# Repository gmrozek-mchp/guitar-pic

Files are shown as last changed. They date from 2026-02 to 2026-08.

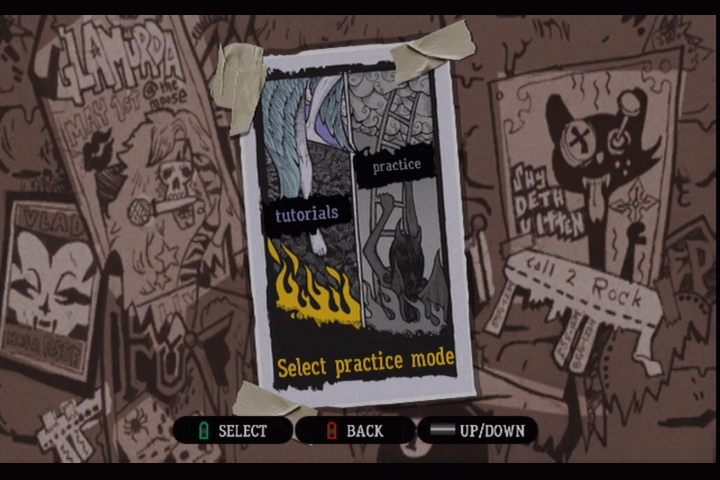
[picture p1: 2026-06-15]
firmware/marvin/docs/gh3_screens/training_menu__tutorials.png

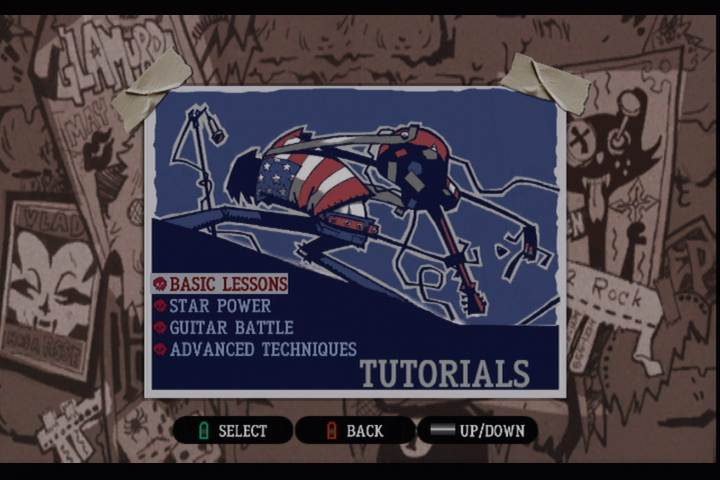
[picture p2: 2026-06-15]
firmware/marvin/docs/gh3_screens/tutorials_menu.png

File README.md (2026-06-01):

# Guitar Hero Bot

An autonomous robot that plays Guitar Hero / Rock Band on a Nintendo Wii by watching the game video, detecting notes in real time, and pressing the buttons on a real Wii guitar controller.

The system is built around a SAM9X75 host (**marvin**) that captures HDMI directly off the Wii, runs reference computer-vision note detection, schedules chord and strum timing, and sends fret/strum commands over USB CDC to a small actuator MCU (**fretboard**) that drives the controller's buttons via open-drain GPIO. A separate Python tool (**fret-tuner**) is used at the bench for calibration and detector tuning, but is not in the runtime path.

For the full system overview see [SPEC.md](SPEC.md).

## Where to start

| If you want to… | Read |
|---|---|
| Understand the whole system | [SPEC.md](SPEC.md) |
| Work on the SAM9X75 host (capture, CV, timing, UI) | [firmware/marvin/docs/spec.md](firmware/marvin/docs/spec.md) + [journal](firmware/marvin/docs/journal.md) |
| Work on the actuator MCU (sensors, GPIO output) | [firmware/fretboard/SPEC.md](firmware/fretboard/SPEC.md) |
| Tune detection algorithms at the bench | [tools/fret-tuner/SPEC.md](tools/fret-tuner/SPEC.md) |
| Inspect marvin performance logs (live or captured) | [tools/marvin-perf/](tools/marvin-perf/) |
| Work on actuator mechanical / PCB / 3D-print parts | [hardware/](hardware/) |

## Repository layout

```
guitar-pic/
├── README.md            # this file
├── SPEC.md              # system spec
├── CLAUDE.md            # workflow rules for Claude Code sessions
├── firmware/
│   ├── marvin/          # SAM9X75 host firmware
│   ├── fretboard/       # PIC32CM6408 sensor/actuator MCU
│   └── sam9x75_curiosity_emirror/   # Microchip reference (template only)
├── tools/
│   ├── fret-tuner/      # Python dev/calibration tool
│   └── marvin-perf/     # marvin performance-log decoder + web viewer
├── hardware/            # PCB, mechanical, actuator design
└── docs/
    ├── SAM9X7-Series-Data-Sheet-DS60001813.pdf
    └── archive/         # historical docs from the original architecture
```

## Status

Working end-to-end: marvin captures HDMI (480p60 and 720p60) and displays live on the LVDS panel; the reference CV detector (`cv_marvin_v1`) runs on captured frames; the timing pipeline and fretboard link (USB CDC over EDBG) are up and gameplay has been tested on Expert and Easy difficulty. The perf-log USB CDC export streams RTOS analytics and pixel strips to a browser-based viewer (`tools/marvin-perf`). Fretboard standalone play (phototransistors + open-drain GPIO) remains operational as a fallback.

In progress: SD-card reference-data recording (M4), full operator UI (M5+). Phasing detail in [SPEC.md §7](SPEC.md).

## License & acknowledgments

MIT License. Hobby / educational project. Guitar Hero and Rock Band are trademarks of Activision and Harmonix; Wii is a trademark of Nintendo.

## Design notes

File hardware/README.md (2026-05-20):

# hardware/

Physical-build artifacts for the guitar-playing robot — PCB, mechanical, and actuator design.

| Folder | What's there |
|---|---|
| [`actuators/`](actuators/) | Design + test-protocol docs for three candidate fret/strum actuator types. The actuator choice is intentionally still open. |
| [`3d-models/`](3d-models/) | OpenSCAD sources and STLs for printed actuator parts. |
| [`Sensor-LCD5/`](Sensor-LCD5/) | KiCad project for the fretboard sensor/actuator PCB (5 phototransistors + open-drain GPIO outputs to a Wii guitar controller). |
| [`kicad/`](kicad/) | Shared KiCad symbol and footprint libraries used by `Sensor-LCD5/` and any future boards. |

## Actuator candidates

Three options are documented under `actuators/`. Each has a design doc and a test-protocol doc.

| Type | Pros | Tradeoffs |
|---|---|---|
| **Voice coil** ([design](actuators/voice-coil-design.md), [test](actuators/voice-coil-test-protocol.md)) | Quietest, fastest, supports proportional control | Most complex to build; custom-wound coil + magnet |
| **Electromagnet** ([design](actuators/electromagnet-design.md), [test](actuators/electromagnet-test-protocol.md)) | Very quiet, simple construction, no moving driver coil | Lower force per watt than a solenoid |
| **DIY solenoid** ([design](actuators/diy-solenoid-design.md)) | Well-understood, predictable behavior | Loudest of the three |

Test protocols measure response time, force, and acoustic noise so the candidates can be compared apples-to-apples before a final pick.

## How this folder relates to firmware

The actuator design docs describe physical drive characteristics (force, response time, current draw). They do not describe the software command path — that lives in the firmware specs:

- The actuator's GPIO-side interface (open-drain pin assignment, pulse durations) is defined by [`firmware/fretboard/SPEC.md`](../firmware/fretboard/SPEC.md).
- The chord and strum scheduling that produces those pulses is described by [`firmware/marvin/docs/spec.md`](../firmware/marvin/docs/spec.md) §4.4.

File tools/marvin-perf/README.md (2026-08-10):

# marvin-perf

Host-side decoder and analyzer for the marvin firmware **perf-log** wire format.

The firmware emits framed binary records (schema version 7) over its USB-device
CDC ACM port. This tool consumes that stream live, records it to disk, and
replays captures offline. Summary analyses (latency attribution, drop
accounting, stack high-water trends) are produced by the `serve` viewer, not a
standalone CLI verb.

Wire format source-of-truth lives in the firmware tree at
[`firmware/marvin/default/src/perf_log/perf_log_records.h`](../../firmware/marvin/default/src/perf_log/perf_log_records.h).
The Python schema mirror in [`marvin_perf/records.py`](marvin_perf/records.py)
must match it byte-for-byte; bump `EXPECTED_SCHEMA_VERSION` (Python side) and
`PERF_LOG_SCHEMA_VERSION` (firmware side) together.

## Setup

All Python work runs through [**uv**](https://docs.astral.sh/uv/). First-time
bootstrap:

    cd tools/marvin-perf
    uv sync --group viewer   # include viewer deps for the serve command

`uv sync` creates `.venv/` and writes `uv.lock`. Subsequent invocations use the
existing venv automatically. Omit `--group viewer` if you only need the headless
CLI helpers (record, set-mask, set-overlay, snapshot, screendump, export-ml).

## Usage

    # Launch the visual review server (default when no subcommand is given)
    # In live mode the SCORE / 2P SC L / 2P SC R toggles each start one device
    # region slot; hit Record to capture them into the .bin like any other
    # record, then extract them offline with `export-region --kind`.
    uv run marvin-perf
    uv run marvin-perf serve
    uv run marvin-perf serve --host 0.0.0.0 --port 8765
    uv run marvin-perf serve --capture session.bin   # pre-load a capture on startup

    # Capture raw bytes from the marvin USB-device CDC port
    uv run marvin-perf record --port /dev/cu.usbmodem... --out session.bin
    uv run marvin-perf record --port /dev/cu.usbmodem... --out-dir session/   # perf.bin + manifest.json

    # Push a type-mask to a running device without attaching for capture
    uv run marvin-perf set-mask --port /dev/cu.usbmodem... --types ALL

    # Toggle the per-fret target rings on the SENSING strip
    uv run marvin-perf set-overlay --port /dev/cu.usbmodem... --on

    # Capture one full video frame from a running device and save it
    uv run marvin-perf snapshot --port /dev/cu.usbmodem... --out snapshots/

    # Dump a UI framebuffer (Legato canvas surface) — the counterpart to snapshot
    uv run marvin-perf screendump --port /dev/cu.usbmodem... --canvas dash
    uv run marvin-perf screendump --port /dev/cu.usbmodem... --canvas navigation
    uv run marvin-perf screendump --port /dev/cu.usbmodem... --canvas navigation \
        --rect 12,120,296,56 --out drawer-row.png

    # Stream a fixed sub-region (default: the scoring block) to PNGs at full rate
    uv run marvin-perf score-capture --port /dev/cu.usbmodem... --out scores/ --count 500
    uv run marvin-perf score-capture --port /dev/cu.usbmodem... --rect 114,309,96,105

    # ...or one of the two 2-player amp scoreboards (independent device slots,
    # so both can stream at once from separate invocations)
    uv run marvin-perf score-capture --port /dev/cu.usbmodem... --slot score-2p-left
    uv run marvin-perf score-capture --port /dev/cu.usbmodem... --slot score-2p-right

    # Extract strips of one kind from a recorded capture into <prefix>-NNNNN.png
    # (5-digit, so a lexicographic sort is frame order up to 99999 frames)
    uv run marvin-perf export-region session/ --out scores/
    uv run marvin-perf export-region session/ --kind score-2p-left --out scores-2pL/
    uv run marvin-perf export-region session/ --kind sensing-2p --out bands-2pL/

### `snapshot` vs `screendump`

They read two memories that share nothing, so neither can show the other's pixels:

* **`snapshot`** captures the **video frame** (the HDMI capture on the HEO hardware
  layer). Use it for anything about what the camera/console is producing.
* **`screendump`** captures a **Legato canvas surface** — the UI framebuffer a screen
  renders into. Use it to inspect widgets, icons and text at the pixel level.

`screendump` takes `--canvas` because every canvas is its own surface: the nav drawer,
the song/mode dialog, the album-art strip and the on-screen keyboard are **not** part
of the base view's buffer. Dump the canvas that owns the pixels you want.

Neither reproduces the panel: the LCDC composites the hardware layers (BASE / HEO /
OVR1 / OVR2) in the display controller, so the blended result exists only on the
glass. `screendump` deliberately does not try to fake it.

    # Export a capture as a SensiML-format CSV for MPLAB ML training
    uv run marvin-perf export-ml session/ --out session.csv --labels actuator-fb

### Capturing 2-player gameplay

Two-player mode moves everything the host cares about: the robot reads the
**left** highway instead of the centered one, and the single bottom-left scoring
block is replaced by **two amp scoreboards** near the top of the frame.

The detector's band strips are tagged per highway, so a capture says which
geometry produced them — `sensing`/`strike` for the 1p centered highway,
`sensing_2p`/`strike_2p` for the 2p left (robot) one. The switch is automatic
during a 2p song (marvin's screen classifier) and forceable from marvin's console
with `cvcfg 2pl`. Both kinds are gated by the STRIP type mask, as before.

The scoreboards ride the region-stream slots. The device has three independent
slots, each with its own enable and rect, each emitting its own strip kind:

| slot | `--slot` / `--kind` | strip kind | default rect |
|---|---|---|---|
| 0 | `score` | `region` | `114,309,96,105` (1p scoring block) |
| 1 | `score-2p-left` | `score_2p_left` | `128,164,68,78` |
| 2 | `score-2p-right` | `score_2p_right` | `515,164,68,78` |

Rects are host-supplied, so any slot can be repointed without a firmware
rebuild. Every slot streams at the full frame rate and there is no rate control:
over-subscribing the wire drops strips at the device's strip pool, counted in
`DROP.dropped_strip`. Capture the note bands and the scoreboards in **separate
sessions** rather than trying to fit both.

## Tests

    uv run pytest

Fixtures under [`tests/fixtures/`](tests/fixtures/) are hand-built byte streams
covering one frame per record type plus framing edge cases (FCS mismatch,
truncated payload, mid-stream join needing SOF resync).

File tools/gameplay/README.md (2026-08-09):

# gameplay — GH3 game-state engine (offline prototype)

Host-side prototype for marvin's game-state observer/controller (spec §4.8, milestone
M9/M10). Algorithms are proven here against the real-screen corpus, then the proven,
simple logic ports to a firmware `gameplay_engine` module. See
[`docs/journal.md`](docs/journal.md) and `firmware/marvin/docs/gh3_navigation.md`.

So far:
- **Screen classifier** — which GH3 screen is this (`main_menu`, `song_select`, `in_song`,
  …) or `UNKNOWN`.
- **Static-list selection reader** — within a recognized static-list screen, which menu
  item is highlighted.
- **song_select reader** — which song is in the highlight slot (and which setlist).
- **Navigator (M10)** — plan a high-level verb (practice-run a song on a difficulty) and
  execute it closed-loop along the menu graph, verified against a simulated menu and the real
  observer.

## Screen classifier

Coarse **fixed-region colour fingerprint** + **nearest-centroid** classifier with an
**UNKNOWN reject** rule (Q10: fixed-region matching, not general CV). A frame is split
into a `cols×rows` grid; each region collapses to its mean BGR; the concatenated vector
is compared by integer L1 distance to one centroid per screen class. The design is shaped
to port to cheap integer C and is **memory-bound, not compute-bound** on the SAM9X75.

Two knobs (chosen empirically by `gameplay eval`, defaults baked into `FingerprintConfig`):

- **sample density** — dense (every pixel; ~7–20 ms on-device) vs a sparse N×N lattice per
  region (sub-millisecond). Default: 5×5 lattice.
- **normalization** — per-frame value standardization, which cancels the **gain/offset
  value-slop** of the Wii's analog-component → HDMI path. Default: on (it is what lifts
  slop-robustness to ~99.8%).

Default config (12×8, 5×5 samples, normalized): 96% leave-one-out accuracy (= 100% of all
multi-sample classes; the 4 single-sample classes can't be LOO-matched), ~99.8% robustness
across the synthetic analog-slop envelope, ~0.1–0.4 ms estimated per classification.

## Static-list selection reader

For the 8 fixed-count static-list screens, per-screen menu metadata (ordered items +
menu-band geometry, in `metadata.py`) divides the band into one cell per item. The selected
cell is the one that deviates most from its **unselected baseline** (learned per screen from
the corpus) — GH3 marks selection by *changing* a row (colour/bar), not by making it
brightest, so "what changed" is the robust signal. Cell colours are normalized per frame to
cancel gain/offset slop. Result: 100% clean / ~99.4% slop on the 33 labelled frames.

## song_select reader

The selected song sits in a fixed highlight slot (except each setlist's first song, which
sits one row lower). We identify it by matching the slot's low-res grayscale bitmap against
the 64 per-song templates — across **both** setlists, so main/bonus falls out of the match.
A small read-time offset search re-aligns the slot, which makes the fine grid tolerant of
positional slop. Result: 64/64 clean, ~99.1% under slop. The active setlist is also read
independently from the page background colour (main = yellow, bonus = white; warmth R−B):
100% clean and under slop.

Char-level OCR is deliberately out of scope: menu items and song titles are a closed set we
already have reference bitmaps for (match, don't decode); digit OCR comes only with score
reading. `section_select` (variable list) and reading the scrolling neighbour list are deferred.

## 2-player amp scoreboard reader

Two-player mode replaces the single bottom-left scoring block with two amp scoreboards near
the top of the frame. `amp2p.py` registers each side independently against its static chrome
(hand-painted `amp2p_<side>_mask.png`), then reads the green LED score inside the registered
block. The strip is a **fixed grid** — 7 px cells at pitch 9, band rows 14–23, right-aligned
against a fixed edge — so there is no ink segmentation: cell positions come from `AMP2P_GRID`
and each is matched by integer coverage L1 against a template bank. Two details carry the
accuracy: the ink threshold is relative to *each cell* (the LEDs pulse, and a band-wide
threshold thins a dim `9` into a `5`), and each digit keeps **two** templates rather than one
average (its bloomed and thin renderings). The font is not segment-decodable — `1` is a centred
bar, `4` and `7` have diagonals.

Which cells hold a digit is read off the display, not the matcher: unused leading cells are
unpowered, so a per-cell contrast gate gives the digit count. Anything the grid cannot justify
— a non-right-aligned lit pattern, a digit count outside the table, ink off the grid — returns
no value with `layout_unknown` set, rather than a guess. Result: **3027/3027** frames of the
reference right-side capture read with 0 monotonic violations, and a bank built from 10
committed right-side frames reads the **left** amp in all 5 corpus snapshots exactly.

Deferred (see `docs/journal.md`): star-power pill count, the centre face-off gauge, and the
multiplier. Scores above 99999 re-lay-out the strip and are flagged, not read.

## Navigator (M10)

`navgraph.py` encodes the menu graph (`firmware/marvin/docs/gh3_navigation.md`) as data;
`navigator.py` plans a verb (`plan_practice_run`, `plan_goto`) and runs it closed-loop through
an `Observer`/`Actuator` seam. The controller is observation-driven — each step runs against
the screen actually observed — which yields normal progress, the `part_select` skip, and RED
recovery from one rule. Offline it's driven by `simgame.py` (the test oracle); on the device
the same seam takes the CV observer + fretboard link. Selections strum the signed delta from
the observed cursor (sticky-safe); FULL SONG/FULL SPEED strum up until the selection stops
moving (no blind count).

## Usage

```sh
uv sync --group dev

uv run gameplay eval                 # classifier + selection reader: accuracy, robustness, thresholds, HW time
uv run gameplay eval --no-sweep      # skip the parameter sweep
uv run gameplay classify path/to/frame.png   # screen id (+ selection / song)
uv run gameplay rows path/to/frame.png       # debug per-cell selection scores
uv run gameplay read-score path/to/frame.png            # 1p score reader on one frame
uv run gameplay read-amp2p path/to/frame.png --side left  # 2p amp score reader on one frame

# 2p amp capture workflow (marvin-perf provides the frames)
#   cd ../marvin-perf && uv run marvin-perf export-region <cap> --kind score-2p-left --out /tmp/L
uv run gameplay amp2p-monotonic /tmp/L --side left      # label-free sweep over a whole capture
uv run gameplay amp2p-grow /tmp/L --side left           # propose new corpus frames (add --commit)

uv run gameplay navigate --song 19 --difficulty hard   # plan + run a practice run vs the sim
uv run gameplay export-c --out gameplay_metadata.h     # freeze recognizer metadata to a C header

uv run pytest
```

## Firmware port (marvin `gameplay_engine`, spec §4.8)

The proven algorithms are being ported to marvin firmware in phases (see `docs/journal.md`).
Phase 0 (done) is `gameplay export-c`: it emits all recognizer data — classifier
centroids/thresholds, static-list menu geometry + baselines, song templates/ROIs — as a single
generated C header (`gameplay_metadata.h`, plain PODs + flat arrays) that the firmware compiles
in. Floats are only the per-frame-normalized baselines/song vectors (soft-float on the ARM926).
The generated header is verified to compile under `cc -std=c11 -Wall -Wextra`.

The corpus is read from `firmware/marvin/docs/gh3_screens/` (override with
`$GAMEPLAY_CORPUS_DIR`). Labels come from each filename's prefix.

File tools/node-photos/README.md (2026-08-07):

# node-photos

Prepares the per-node board photos shown on marvin's **System Info** detail screen.

Drop one photo per node in `data/`, named for the node, then:

```bash
cd tools/node-photos
uv run process_node_photos.py
```

That writes `288x620` PNGs into `firmware/marvin/data/system/nodes/`, which is the
card image tree — copy it to the SD card (or point `--out` straight at the card).

Node names must match the `PHOTO` table in
`firmware/marvin/default/src/ui/node_art.c`:

```
marvin  fauxmote  guitar  fretboard  beatbox  lemmy  lightshow  guitar-pic
```

`guitar-pic` is the whole-rig shot for the project card rather than a node — the
firmware keys it off `0xFF`, outside the T1S id space.

## The frame is baked in

Each output carries its own 1px rounded border (`#404040`, radius 4, corners eaten back to page
black). That is not decoration you can drop: the photo is scanned out on its own hardware layer
above the UI canvas — which is how it keeps 8 bits per channel instead of being quantized to
RGB565 — so no widget can draw a frame over it. Staying opaque over the whole rect is also what
lets the firmware tell the display controller to skip reading the canvas underneath.

Nodes with no photo keep an empty frame drawn by the UI instead.

## Why this step isn't optional

The firmware reads the PNG header and **skips any file that isn't exactly
288x620** (`NODE_ART_W` x `NODE_ART_H` in `ui/node_art.h`), leaving that node's
photo slot empty and the detail screen showing a blank frame. It also has to be PNG:
Legato's JPEG decoder gates its block writes on the renderer clip rect, which is
stale during marvin's offscreen boot decode, so a runtime JPEG decodes to noise.

A missing photo is fine — the loader never fails boot, and the card just reads blank.

## Fit modes

The photo column is tall and narrow (~1:2.15), which almost no camera photo is.

- `--fit contain` (default) — scale the whole photo to fit and letterbox the rest in
  the card's own zinc-900, so the board stays recognizable. Right for landscape shots.
- `--fit cover` — centre-crop to fill the column. Right for a photo already framed
  portrait.

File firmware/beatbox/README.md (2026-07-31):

# beatbox

The **beat-source node** for the Guitar Hero Bot system — a Microchip
**dsPIC33AK512MPS512** DSC that listens to line-level audio, runs real-time FFT
beat detection, and publishes the result to the animation and lighting nodes over
10BASE-T1S: **position commands → [`lemmy`](../lemmy)** and a compact **beat frame →
[`lightshow`](../lightshow)**. It is the system's ear and its choreography brain;
it drives no actuator on the bus itself.

Imported from the standalone `dspicguitarhero` head-banging animatronic and rebuilt
on a fresh MCC config for the MPS512.

## What works today (on the bench)

- **Audio in → beat events.** ADC4 samples stereo line-in at 48 kHz; a 512-point FFT
  extracts spectral-flux / envelope / kick features; a two-band onset detector emits
  discrete beat events. See **[`docs/beat-detection.md`](docs/beat-detection.md)** for
  how the whole chain works.
- **Audio passthrough** to the PWM DACs (RB8/RB9) — a monitor/scratch output, not a
  clean speaker feed (hiss in both the ADC and PWM stages; see the journal).
- **Live RGB indicator.** The onboard LED flashes on beats (kick = white, bass = red,
  mid/high = blue) — a quick visual check that detection is tracking the music.
- **UART2 CLI** for bench control and diagnostics (below).
- **10BASE-T1S PLCA follower (id 5).** Brings up the LAN8651 MAC-PHY, syncs PLCA, and
  announces presence via a heartbeat once a coordinator is on the wire.

Not yet done: publishing beat frames / position commands **on the bus** (milestone
B4), and the **tempo/BPM + phase** layer those need. The imported puppet-motion and
WS2812 effects remain parked in `config.mcc.bak/`.

## Architecture at a glance

Strictly layered, each stage feeding the next; a single stereo sample callback
decouples audio capture from analysis:

```
audio (I/O) → beat_detect (FFT features) → beat_engine (decision) → tempo/phase (later)
```

The heavy DSP runs in the main loop, not the ISR — the 48 kHz ADC interrupt only
buffers samples and hands off via `volatile` flags. Full write-up, including the
no-RTOS cooperation model, in [`docs/beat-detection.md`](docs/beat-detection.md).

| Module (`config.mcc/src/`) | Role |
|---|---|
| `audio.{c,h}` | 48 kHz ADC ISR, DC-block HPF, PWM passthrough, sample callback |
| `beat_detect.{c,h}` | downsample + 512-pt FFT + flux/envelope/kick feature extraction |
| `beat_engine.{c,h}` | onset decision over the features → publishes a `BeatFrame` |
| `t1s_follower.{c,h}` | OA-TC6 / LAN8651 10BASE-T1S PLCA follower |
| `rgb_led.{c,h}` | onboard RGB LED (three SCCP PWM channels) |
| `cli.{c,h}` | UART2 command line (embedded-cli) |

## CLI

Over UART2 (`beatbox>` prompt):

| Command | Purpose |
|---|---|
| `info` | node identity / bring-up state |
| `beat` | latest beat frame — envelope, bass/full flux, kick, beat flags |
| `audio` | raw + filtered L/R sample and peak-to-peak envelope |
| `rgb <r> <g> <b>` / `rgb off` | set the onboard RGB LED (0–255) |
| `t1s` / `t1s id` / `t1s plca` | T1S link status; MAC-PHY id / PLCA diagnostics |
| `reset` | software reset |

## Build

Toolchain: **XC-DSC v3.31**. Build with CMake → Ninja (MPLAB project `beatbox`):

```
cmake -G Ninja \
  -DCMAKE_TOOLCHAIN_FILE=cmake/beatbox/default/.generated/toolchain.cmake \
  -B _build/beatbox/default \
  cmake/beatbox/default
cd _build/beatbox/default && ninja
```

Artifacts: `out/beatbox/default.elf` and `.hex` (flashable). The `cmake/` project tree
is regenerated by MPLAB from `.vscode/beatbox.mplab.json`; `_build/`, `out/`, and
`cmake/**/.generated/` are generated (see [`.gitignore`](.gitignore)).

## Docs

- **How the signal chain works:** [`docs/beat-detection.md`](docs/beat-detection.md)
- **What it is / design / milestones:** [`SPEC.md`](SPEC.md)
- **Decisions & progress:** [`docs/journal.md`](docs/journal.md)
- **System context:** top-level [`SPEC.md`](../../SPEC.md)

## Layout

| Path | Purpose |
|---|---|
| `config.mcc/` | Firmware sources (`src/`) + MCC config (`mcc/`) + generated tree (`mcc_generated_files/`, do not edit) |
| `cmake/` | Generated CMake project (`beatbox/default/`) |
| `.vscode/` | MPLAB project file + workspace settings |
| `docs/` | Signal-chain doc + working journal |
| `SPEC.md` | Specification |

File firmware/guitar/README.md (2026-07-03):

# guitar

Wii-guitar **actuator node** for the Guitar Hero bot's T1S bus. A PIC32CM PL10
(10BASE-T1S PLCA follower) that receives a 1-byte button bitmask from
[marvin](../marvin/) and drives a real Wii guitar controller via open-drain GPIO.

It is the actuation half of the original [fretboard](../fretboard/) firmware, split
onto its own node so sensing (detector nodes) and actuation (guitar nodes) are
separate node classes on one PLCA bus.

- **What it is / firmware design:** [`SPEC.md`](SPEC.md)
- **Decisions + progress:** [`docs/journal.md`](docs/journal.md)
- **System context:** top-level [`SPEC.md`](../../SPEC.md), [`docs/t1s-podl-link.md`](../../docs/t1s-podl-link.md)

Status: working on hardware — the T1S PLCA follower is up, receives and actuates
marvin's command over T1S, and runs a presence heartbeat plus a debug-UART CLI.
See [`SPEC.md`](SPEC.md) for the current milestone state.

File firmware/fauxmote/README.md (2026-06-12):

# fauxmote

ESP32 firmware that emulates a Nintendo Wiimote (with a Guitar Hero guitar
extension) to a real Wii console, on an **Adafruit ESP32 Feather V2** (product 5400).

See [`SPEC.md`](SPEC.md) for what this is and [`docs/journal.md`](docs/journal.md)
for the running plan, decisions, and open questions.

## Build & flash (ESP-IDF v6.x — developed against v6.0.1)

```sh
. $IDF_PATH/export.sh          # activate the ESP-IDF environment
idf.py set-target esp32        # original ESP32 (Feather V2) — has Bluetooth Classic
idf.py build flash monitor     # build, flash over USB-C, open the serial log
```

The board comes up as `Nintendo RVL-CNT-01` and, on a Wii red-SYNC press, pairs and
opens both HID channels (custom SDP record + raw L2CAP; see [`SPEC.md`](SPEC.md) §5
and the journal). Responding to the Wii's reports so it stays an assigned, live
Wiimote is Phase 2.

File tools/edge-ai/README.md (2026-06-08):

# edge-ai

Distill marvin's emitted gameplay commands into a small causal model over the
fretboard's 5-channel ADC stream. **Design + plan live in [`docs/`](docs/)** —
start with [`docs/SPEC.md`](docs/SPEC.md) and [`docs/journal.md`](docs/journal.md).

This package is the host-side pipeline (PyTorch): train a causal CNN, then int8
post-training quantise it into the `model_weights.h` the fretboard firmware runs.
Input is the actuator-labelled CSV from `marvin-perf export-ml --labels=actuator-fb`.

## Layout

- `edge_ai/data.py` — CSV loader + causal row-index windowing (stdlib).
- `edge_ai/lag.py` — photo-dip → strum lag measurement (stdlib).
- `edge_ai/metrics.py` — per-bit accuracy/F1 + strum-event timing (stdlib).
- `edge_ai/model.py` — causal 1D-CNN (`StrumNet`, torch).
- `edge_ai/train.py` — training loop + holdout evaluation (torch).
- `edge_ai/quantize.py` — int8 post-training quantiser + `model_weights.h` emitter (numpy/torch).
- `edge_ai/viz.py` — torchinfo summary, torchview graph, receptive-field cone plot (`viz` group).
- `edge_ai/cli.py` — `edge-ai {lag,train,eval,quantize,viz}`.

The stdlib pieces (`data`, `lag`, `metrics`) run without numpy/torch; only
`model`/`train`/`eval` need the `train` dependency group.

## Use

```sh
export UV_CACHE_DIR="$TMPDIR/uv-cache"   # only needed inside a restricted sandbox

# size the causal window from real data (no torch needed)
uv run edge-ai lag path/to/song-expert.csv --curve

# install the heavy deps and train
uv sync --group train --group dev
uv run edge-ai train --holdout heldout.csv song1.csv song2.csv song3.csv \
    --window 60 --out model.pt
uv run edge-ai eval --model model.pt heldout.csv

# int8 quantise -> firmware header (deploy model: --no-holdout --channels 16 --window 85)
uv run edge-ai quantize --model model.pt --name hard \
    --strum-thresh 0.80 --out ../../firmware/fretboard/model_weights.h song1.csv song2.csv

# visualise the model (summary + RF cone always; graph needs the graphviz binary)
uv sync --group train --group viz   # adds torchinfo, torchview, matplotlib
uv run edge-ai viz --model model.pt --rf-cone rf_cone.png --graph graph.svg

# tests (stdlib-only; needs the dev group for pytest)
uv run --group dev pytest
```

For block diagrams beyond these, export the float model to ONNX and open it in
[Netron](https://netron.app), or redraw in PlotNeuralNet / NN-SVG.

Corpus is Expert-only, one song held out — see [`docs/training.md`](docs/training.md) §4.

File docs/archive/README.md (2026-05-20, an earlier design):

# docs/archive/

Preserved historical documentation from the project's original architecture (≤ 2026-04). The system has since been re-architected; see the top-level [`SPEC.md`](../../SPEC.md) and the subproject specs for current state.

**Files here are kept for design-rationale reference and are not maintained.** Specifically: hardware part numbers, wiring diagrams, calibration steps, and timing assumptions in these documents reflect the *original* PC-hosted / Elgato-USB-capture / PS2 / single-PIC-actuator design — not the current SAM9X75 (marvin) + PIC32CM6408 (fretboard) split.

## What's here

| File | Era | What it describes |
|---|---|---|
| [`SPEC-original.md`](SPEC-original.md) | 2026-01 → 2026-04 | The original full project spec. PS2/Wii console choice, Elgato HDMI-USB capture into a PC running OpenCV, PIC microcontroller driving solenoid actuators. Carries a 2026-05-20 supersession banner pointing at the live subproject specs. |
| [`README-original.md`](README-original.md) | 2026-01 → 2026-04 | The original landing-page README. Quick-start instructions point at the (now deleted) `vision/` Python pipeline. |
| [`hardware-bom.md`](hardware-bom.md) | 2026-01 era | Bill of materials for the original architecture: PIC, solenoids, drivers, 12 V PSU, Elgato capture, PS2/Wii guitar. Useful as a reference for actuator-side parts (drivers, PSU sizing); the host-side parts (capture device, PC) are obsolete. |
| [`wiring-diagram.md`](wiring-diagram.md) | 2026-01 era | Electrical interconnects for the PC ↔ PIC ↔ console era. Pinouts and signal levels are valid as physical-electrical reference; topology is obsolete. |
| [`calibration.md`](calibration.md) | 2026-01 era | Timing-calibration procedure assuming the PC-based scheduler in the now-deleted `vision/` folder. Marvin handles timing on-device; calibration UI for the new architecture lives in marvin (TBD, marvin spec §4.5). |

## Why these are preserved (not deleted)

- The actuator-side design rationale (driver topology, PSU sizing, mechanical mounting, phototransistor placement) is still relevant to the current architecture.
- Latency budgets, calibration math, and detection-threshold approaches in the original docs informed the timing constants now in fret-tuner / fretboard / marvin specs.
- Historical context is occasionally useful when revisiting a design choice.

## Related deletions

The original Python vision pipeline (`vision/`) and its tests (`tests/`) referenced from `README-original.md` were deleted from the working tree on 2026-05-20. They remain recoverable from git history for anyone who wants to compare the original detection algorithms against marvin's reference detector.

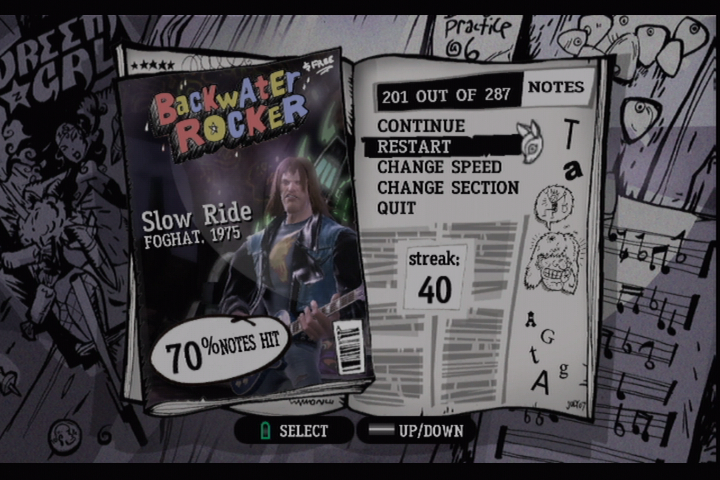
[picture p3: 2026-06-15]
firmware/marvin/docs/gh3_screens/practice_end_menu__restart.png

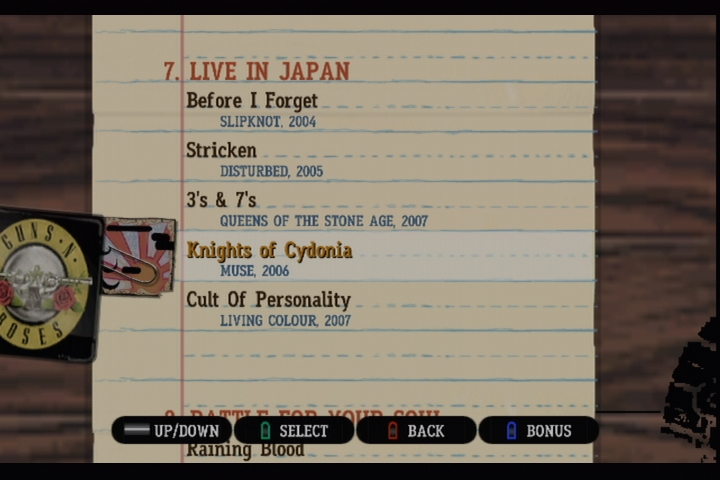
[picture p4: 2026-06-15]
firmware/marvin/docs/gh3_screens/song_select__39_knights_of_cydonia.png

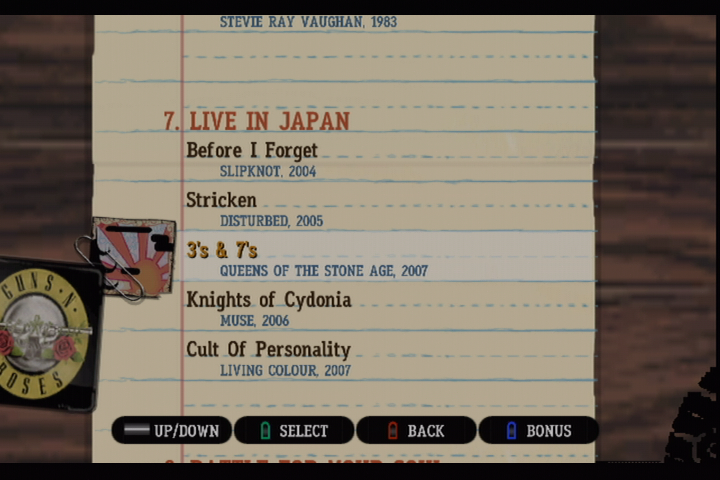
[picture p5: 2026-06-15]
firmware/marvin/docs/gh3_screens/song_select__38_3_s_7_s.png

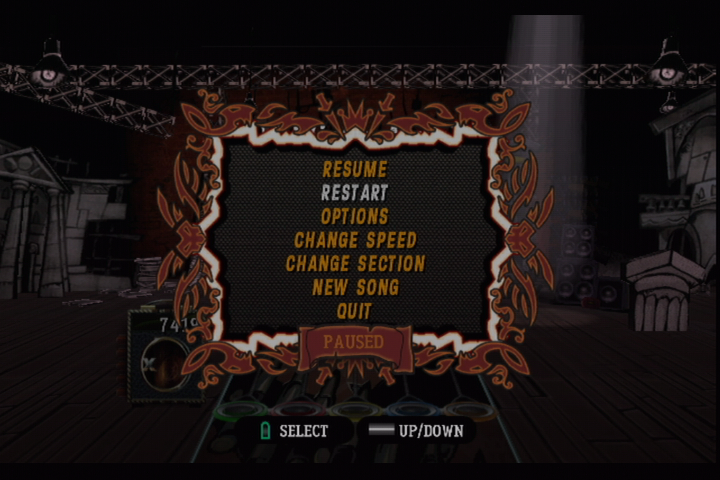
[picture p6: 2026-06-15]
firmware/marvin/docs/gh3_screens/pause_menu__restart.png

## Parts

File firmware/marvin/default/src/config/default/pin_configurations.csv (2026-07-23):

Pin Number | Pin ID | Custom Name | Function | Direction | Latch | Open Drain | PIO Interrupt | Pull Up | Pull Down | Glitch/Debounce Filter | Slew Rate Control | Drive Strength
A2 | PC30 | AC69T88A_ENABLE | GPIO | Out | High | No | Disabled | No | No | Disabled | No | Low
A3 | PC2 | LCD_LVDS_D0_N | LVDSPHY_LVDS_A0M | n/a | n/a | No | Disabled | No | No | Disabled | No | Low
A4 | PC4 | LCD_LVDS_D1_N | LVDSPHY_LVDS_A1M | n/a | n/a | No | Disabled | No | No | Disabled | No | Low
A5 | PC6 | LCD_LVDS_D2_N | LVDSPHY_LVDS_A2M | n/a | n/a | No | Disabled | No | No | Disabled | No | Low
A7 | PC10 | LCD_LVDS_CK_N | LVDSPHY_LVDS_CLK1M | n/a | n/a | No | Disabled | No | No | Disabled | No | Low
A8 | PC12 | LCD_LVDS_D3_N | LVDSPHY_LVDS_A3M | n/a | n/a | No | Disabled | No | No | Disabled | No | Low
A9 | PB19 | QSPI_SCK | QSPI_QSCK | n/a | n/a | No | Disabled | No | No | Disabled | No | Low
A10 | PB17 | LED_8 | GPIO | Out | Low | No | Disabled | No | No | Disabled | No | Low
A11 | PB16 |  | Available | In
B1 | PC28 | LED_5 | GPIO | Out | Low | No | Disabled | Yes | No | Disabled | No | Low
B3 | PC3 | LCD_LVDS_D0_P | LVDSPHY_LVDS_A0P | n/a | n/a | No | Disabled | No | No | Disabled | No | Low
B4 | PC5 | LCD_LVDS_D1_P | LVDSPHY_LVDS_A1P | n/a | n/a | No | Disabled | No | No | Disabled | No | Low
B5 | PC7 | LCD_LVDS_D2_P | LVDSPHY_LVDS_A2P | n/a | n/a | No | Disabled | No | No | Disabled | No | Low
B7 | PC11 | LCD_LVDS_CK_P | LVDSPHY_LVDS_CLK1P | n/a | n/a | No | Disabled | No | No | Disabled | No | Low
B8 | PC13 | LCD_LVDS_D3_P | LVDSPHY_LVDS_A3P | n/a | n/a | No | Disabled | No | No | Disabled | No | Low
B9 | PB21 | QSPI_IO0 | QSPI_QIO0 | n/a | n/a | No | Disabled | No | No | Disabled | No | Low
B10 | PB24 | QSPI_IO3 | QSPI_QIO3 | n/a | n/a | No | Disabled | No | No | Disabled | No | Low
B11 | PB20 | QSPI_CS | QSPI_QCS | n/a | n/a | No | Disabled | No | No | Disabled | No | Low
C1 | PC24 | T1S_nCS | FLEXCOM3_IO4 | n/a | n/a | No | Disabled | No | No | Disabled | No | Low
C2 | PC26 | T1S_SCK | FLEXCOM3_IO2 | n/a | n/a | No | Disabled | No | No | Disabled | No | Low
C4 | PC25 |  | Available | In
C5 | PC27 | LED_6 | GPIO | Out | Low | No | Disabled | No | No | Disabled | No | Low
C7 | PB15 |  | Available | In
C8 | PB23 | QSPI_IO2 | QSPI_QIO2 | n/a | n/a | No | Disabled | No | No | Disabled | No | Low
C10 | PB18 | T1S_IRQ_N | GPIO | In | n/a | No | Falling Edge | Yes | No | Disabled | No | Low
C11 | PB26 |  | Available | In
C17 | PD5 |  | Available | In
D1 | PC20 | LED_BLUE | GPIO | Out | Low | No | Disabled | No | No | Disabled | No | Low
D2 | PC22 | T1S_MOSI | FLEXCOM3_IO0 | n/a | n/a | No | Disabled | No | No | Disabled | No | Low
D3 | PC21 | LED_GREEN | GPIO | Out | Low | No | Disabled | No | No | Disabled | No | Low
D5 | PC29 | LED_7 | GPIO | Out | Low | No | Disabled | Yes | No | Disabled | No | Low
D7 | PC31 |  | Available | In
D8 | PB25 |  | Available | In
D10 | PB22 | QSPI_IO1 | QSPI_QIO1 | n/a | n/a | No | Disabled | No | No | Disabled | No | Low
D16 | PD10 | NAND_D4 | EBI_NANDDAT4 | n/a | n/a | No | Disabled | No | No | Disabled | No | Low
D17 | PB8 |  | Available | In
E1 | PC16 |  | Available | In
E2 | PC18 | LCD_BACKLIGHT_PWM | PWM_PWM0 | n/a | n/a | No | Disabled | No | No | Disabled | No | Low
E3 | PC15 | LED_4 | GPIO | Out | Low | No | Disabled | No | No | Disabled | No | Low
E4 | PC23 | T1S_MISO | FLEXCOM3_IO1 | n/a | n/a | No | Disabled | No | Yes | Disabled | No | Low
E16 | PD14 | NAND_RDY | EBI_NANDRDY | n/a | n/a | No | Disabled | No | No | Disabled | No | Low
E17 | PB14 |  | Available | In
F2 | PC14 | LED_RED | GPIO | Out | Low | No | Disabled | No | No | Disabled | No | Low
F16 | PB6 |  | Available | In
G1 | PC8 | USB_VBUS_SENSE | GPIO | In | n/a | No | Disabled | No | Yes | Disabled | No | Low
G2 | PC0 |  | Available | In
G3 | PC19 |  | Available | In
G4 | PC17 |  | Available | In
G15 | PD3 | NAND_CLE | EBI_NANDCLE | n/a | n/a | No | Disabled | No | No | Disabled | No | Low
G16 | PB0 | LED_2 | GPIO | Out | Low | No | Disabled | No | No | Disabled | No | Low
G17 | PA8 | BUTTON_5 | GPIO | In | n/a | No | Disabled | No | No | Disabled | No | Low
H3 | PC9 |  | Available | In
H4 | PC1 |  | Available | In
H14 | PD1 | NAND_WE | EBI_NANDWE | n/a | n/a | No | Disabled | No | No | Disabled | No | Low
H15 | PD8 | NAND_D2 | EBI_NANDDAT2 | n/a | n/a | No | Disabled | No | No | Disabled | No | Low
H16 | PB2 | BUTTON_6 | GPIO | In | n/a | No | Disabled | No | No | Disabled | No | Low
H17 | PA0 | SDMMC0_DAT0 | SDMMC0_DAT0 | n/a | n/a | No | Disabled | No | No | Disabled | No | Low
J16 | PB4 | LCD_MIPI_SDA | FLEXCOM8_IO0 | n/a | n/a | No | Disabled | No | No | Disabled | No | Low
J17 | PA4 | SDMMC0_DAT2 | SDMMC0_DAT2 | n/a | n/a | No | Disabled | No | No | Disabled | No | Low
K15 | PD12 | NAND_D6 | EBI_NANDDAT6 | n/a | n/a | No | Disabled | No | No | Disabled | No | Low
K16 | PB10 |  | Available | In
K17 | PA2 | SDMMC0_CK | SDMMC0_CK | n/a | n/a | No | Disabled | No | No | Disabled | No | Low
L5 | PA29 | GUITAR_RX | FLEXCOM1_IO1 | n/a | n/a | No | Disabled | No | No | Disabled | No | Low
L13 | PA5 | SDMMC0_DAT3 | SDMMC0_DAT3 | n/a | n/a | No | Disabled | No | No | Disabled | No | Low
L14 | PA11 |  | Available | In
L15 | PB1 | BUTTON_2 | GPIO | In | n/a | No | Disabled | No | No | Disabled | No | Low
L16 | PB12 |  | Available | In
L17 | PA6 | BUTTON_3 | GPIO | In | n/a | No | Disabled | No | No | Disabled | No | Low
M16 | PA10 |  | Available | In
N4 | PA26 | DBGU_RX | DBGU_DRXD | n/a | n/a | No | Disabled | No | No | Disabled | No | Low
N11 | PD0 | NAND_RE | EBI_NANDOE | n/a | n/a | No | Disabled | No | No | Disabled | No | Low
N14 | PD11 | NAND_D5 | EBI_NANDDAT5 | n/a | n/a | No | Disabled | No | No | Disabled | No | Low
N15 | PB5 | LCD_MIPI_SCL | FLEXCOM8_IO1 | n/a | n/a | No | Disabled | No | No | Disabled | No | Low
N16 | PB13 | BUTTON_7 | GPIO | In | n/a | No | Disabled | No | No | Disabled | No | Low
N17 | PA19 | CLASSD_L1 | CLASSD_L1 | n/a | n/a | No | Disabled | No | No | Disabled | No | Low
P8 | PD13 | NAND_D7 | EBI_NANDDAT7 | n/a | n/a | No | Disabled | No | No | Disabled | No | Low
P10 | PD4 | NAND_CS | EBI_NANDCS | n/a | n/a | No | Disabled | No | No | Disabled | No | Low
P11 | PD2 | NAND_ALE | EBI_NANDALE | n/a | n/a | No | Disabled | No | No | Disabled | No | Low
P13 | PD6 | NAND_D0 | EBI_NANDDAT0 | n/a | n/a | No | Disabled | No | No | Disabled | No | Low
P15 | PD7 | NAND_D1 | EBI_NANDDAT1 | n/a | n/a | No | Disabled | No | No | Disabled | No | Low
P16 | PA3 | SDMMC0_DAT1 | SDMMC0_DAT1 | n/a | n/a | No | Disabled | No | No | Disabled | No | Low
P17 | PA17 | T1S_RST | GPIO | Out | High | No | Disabled | No | No | Disabled | No | Low
R1 | PA31 |  | Available | In
R2 | PA25 |  | Available | In
R4 | PA24 |  | Available | In
R5 | PA12 |  | Available | In
R8 | PB3 |  | Available | In
R11 | PD9 | NAND_D3 | EBI_NANDDAT3 | n/a | n/a | No | Disabled | No | No | Disabled | No | Low
R13 | PB7 | BUTTON_4 | GPIO | In | n/a | No | Disabled | No | No | Disabled | No | Low
R14 | PB9 | BUTTON_8 | GPIO | In | n/a | No | Disabled | No | No | Disabled | No | Low
R16 | PA21 | BUTTON_1 | GPIO | In | n/a | No | Disabled | No | No | Disabled | No | Low
R17 | PA18 | CLASSD_L0 | CLASSD_L0 | n/a | n/a | No | Disabled | No | No | Disabled | No | Low
T1 | PA27 | DBGU_TX | DBGU_DTXD | n/a | n/a | No | Disabled | No | No | Disabled | No | Low
T3 | PA30 |  | Available | In
T4 | PA28 | GUITAR_TX | FLEXCOM1_IO0 | n/a | n/a | No | Disabled | No | No | Disabled | No | Low
T5 | PA14 | CLI_RX | FLEXCOM2_IO1 | n/a | n/a | No | Disabled | No | No | Disabled | No | Low
T7 | PA7 | LED_3 | GPIO | Out | Low | No | Disabled | No | No | Disabled | No | Low
T8 | PB11 |  | Available | In
T9 | PA1 | SDMMC0_CMD | SDMMC0_CMD | n/a | n/a | No | Disabled | No | No | Disabled | No | Low
T10 | PA15 | FAUXMOTE_RX | FLEXCOM5_IO1 | n/a | n/a | No | Disabled | No | No | Disabled | No | Low
T11 | PA9 |  | Available | In
U7 | PA20 | BSP_MAXTOUCH_CHG | GPIO | In | n/a | No | Disabled | No | No | Disabled | No | Low
U8 | PA16 | FAUXMOTE_TX | FLEXCOM5_IO0 | n/a | n/a | No | Disabled | No | No | Disabled | No | Low
U9 | PA23 | SDMMC0_CD | GPIO | In | n/a | No | Disabled | No | No | Disabled | No | Low
U10 | PA22 | LED_1 | GPIO | Out | Low | No | Disabled | No | No | Disabled | No | Low
U11 | PA13 | CLI_TX | FLEXCOM2_IO0 | n/a | n/a | No | Disabled | No | No | Disabled | No | Low

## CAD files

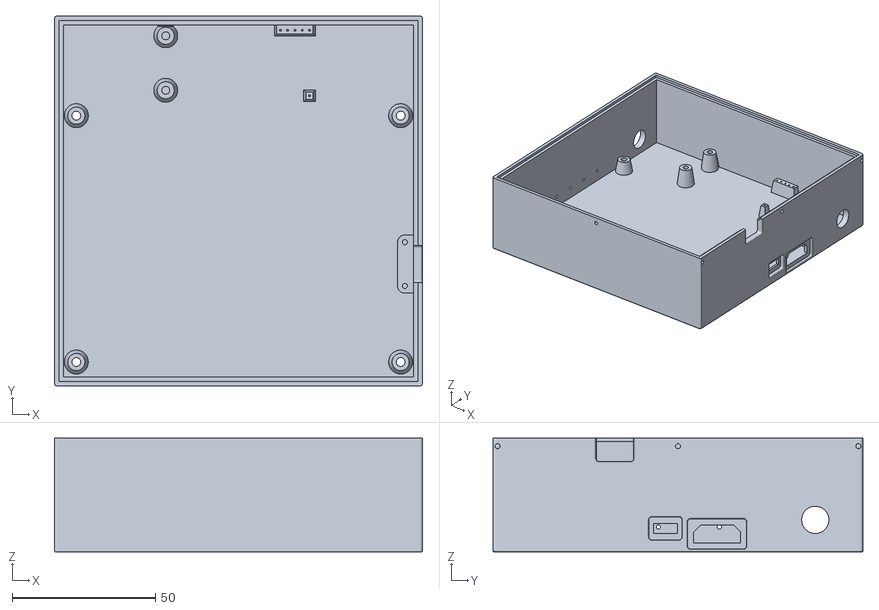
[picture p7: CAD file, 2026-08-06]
hardware/3d-models/Fretboard-Enclosure.stl
128.5 x 129.0 x 39.8

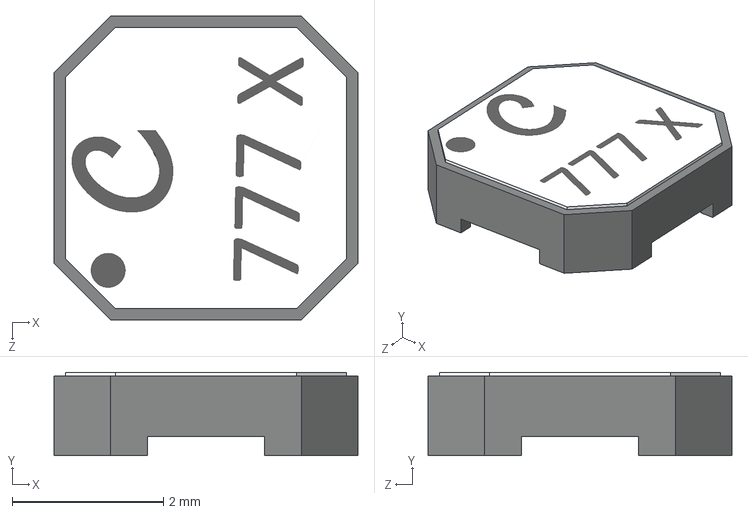
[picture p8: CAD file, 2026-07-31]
hardware/t1s-sink/Coilcraft-LPD4012.STEP
4.02 x 1.10 x 4.02 mm

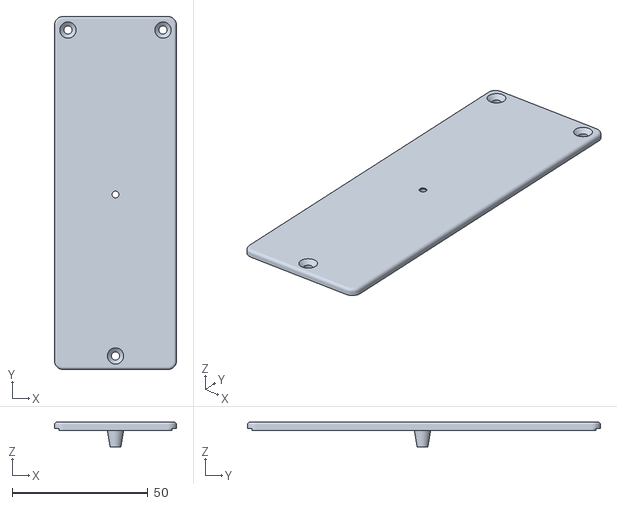
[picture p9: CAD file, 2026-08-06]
hardware/3d-models/EnclosureCover-Lemmy.stl
45.0 x 130.0 x 9.20

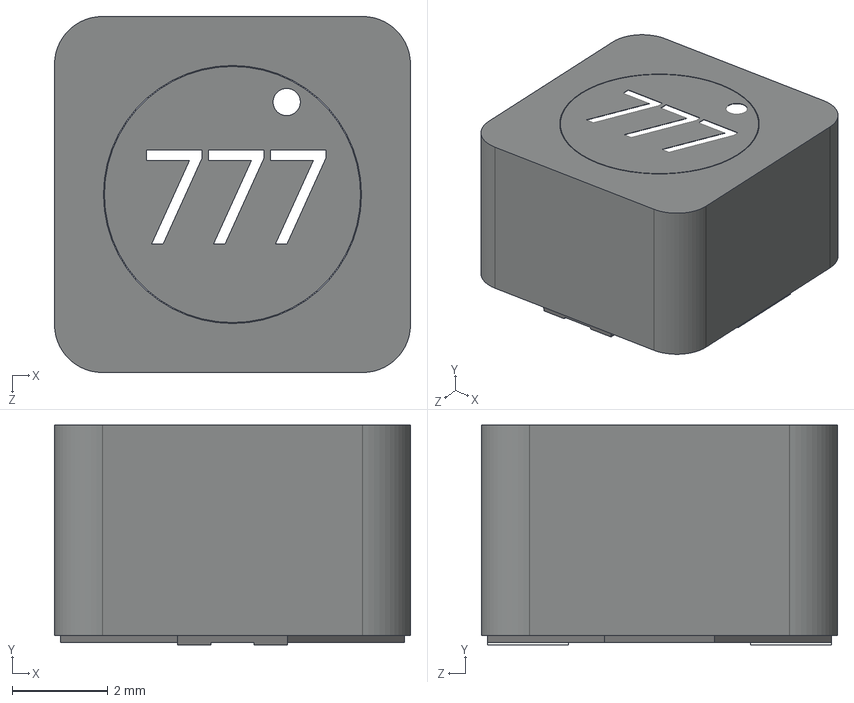
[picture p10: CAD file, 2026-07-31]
hardware/t1s-sink/Coilcraft-MSD7342.STEP
7.45 x 4.60 x 7.45 mm

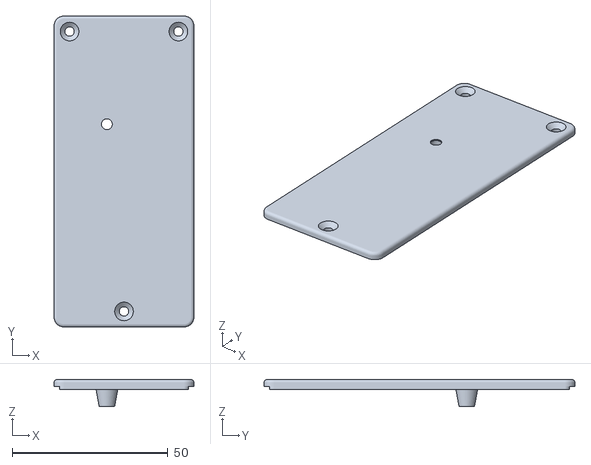
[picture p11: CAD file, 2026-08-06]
hardware/3d-models/EnclosureCover-Fauxmote.stl
45.0 x 100.0 x 8.70

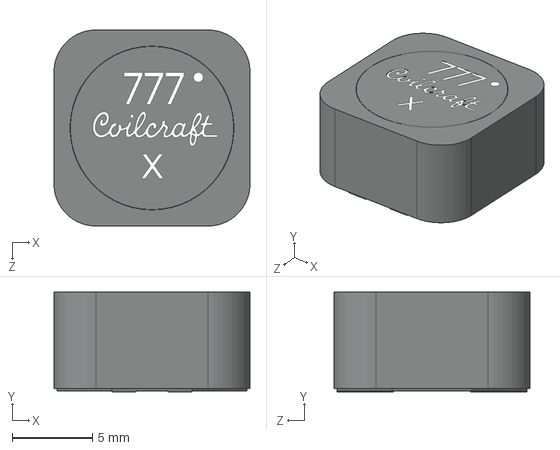
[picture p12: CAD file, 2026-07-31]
hardware/t1s-sink/Coilcraft-MSD1260T.STEP
12.2 x 6.20 x 12.2 mm

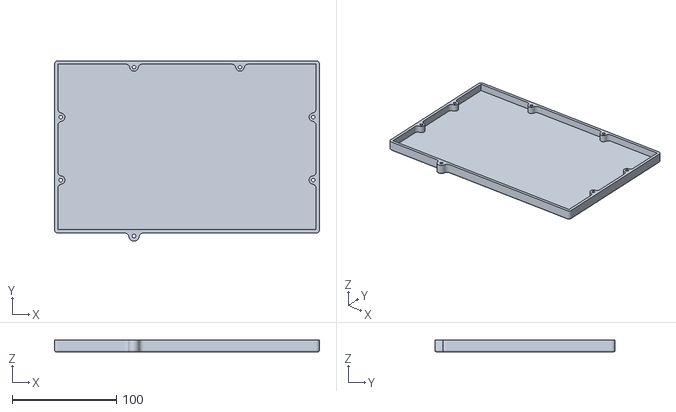
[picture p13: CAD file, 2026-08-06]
hardware/3d-models/Marvin-BackCover.stl
254.0 x 172.9 x 11.2

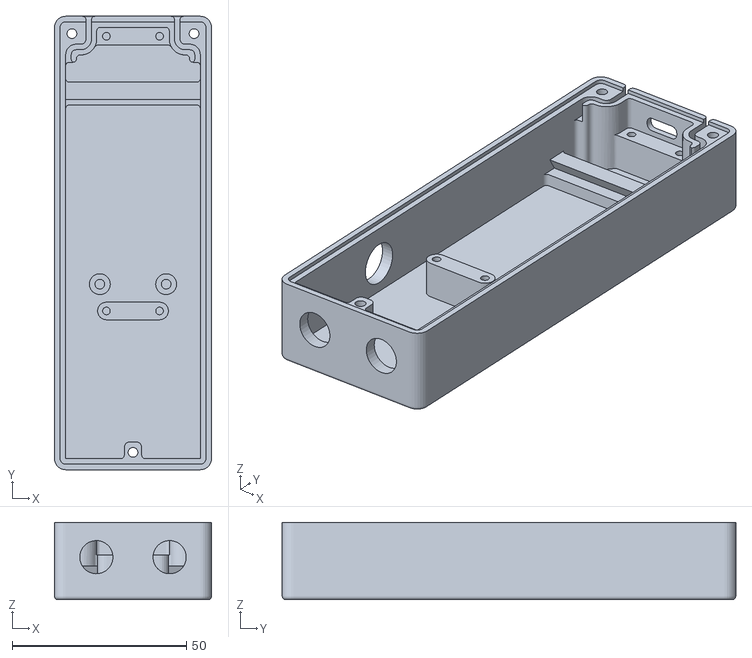
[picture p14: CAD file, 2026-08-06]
hardware/3d-models/Enclosure-Lightshow.stl
45.0 x 130.0 x 22.2

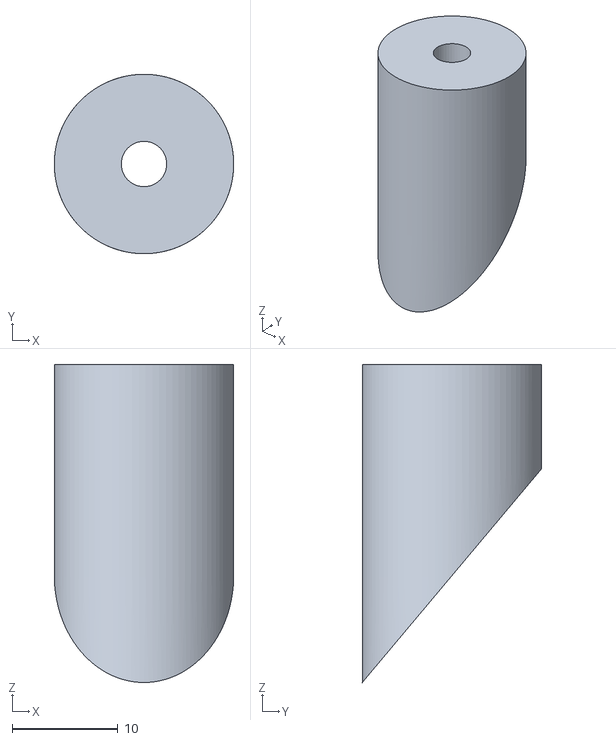
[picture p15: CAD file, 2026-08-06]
hardware/3d-models/LemmyMountTop.stl
17.0 x 17.0 x 30.1

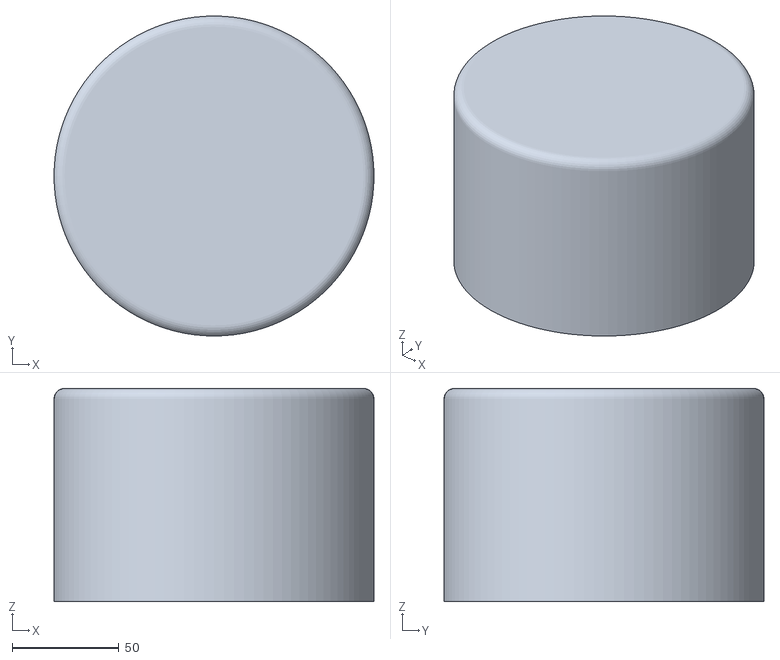
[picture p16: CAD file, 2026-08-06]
hardware/3d-models/HatBlock.stl
150.0 x 150.0 x 100.0

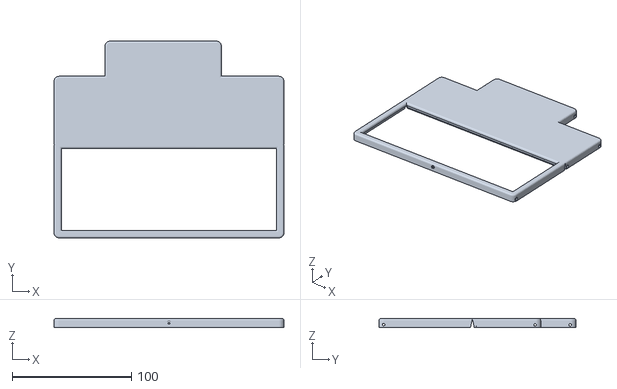
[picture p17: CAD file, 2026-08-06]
hardware/3d-models/BeatBox-Cover.stl
193.3 x 165.4 x 7.61

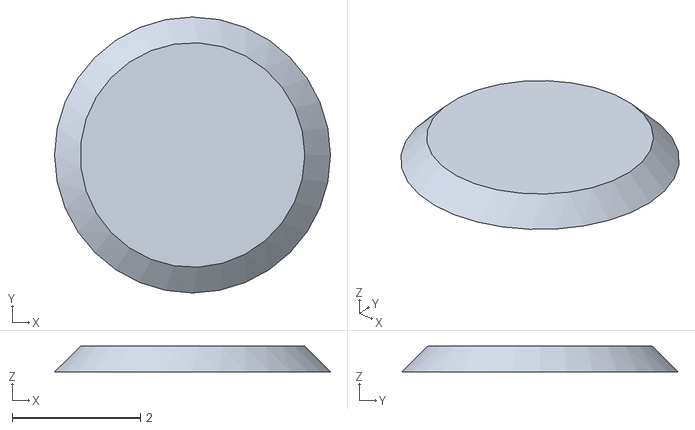
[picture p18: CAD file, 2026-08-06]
hardware/3d-models/EnclosureCover-Fauxmote-LED.stl
4.30 x 4.30 x 0.4

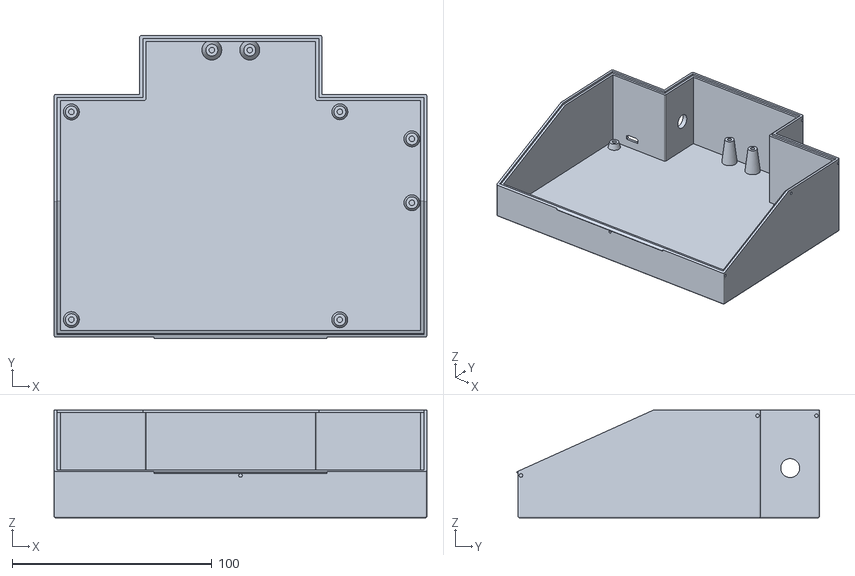
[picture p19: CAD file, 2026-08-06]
hardware/3d-models/BeatBox-Enclosure.stl
186.9 x 152.0 x 54.1

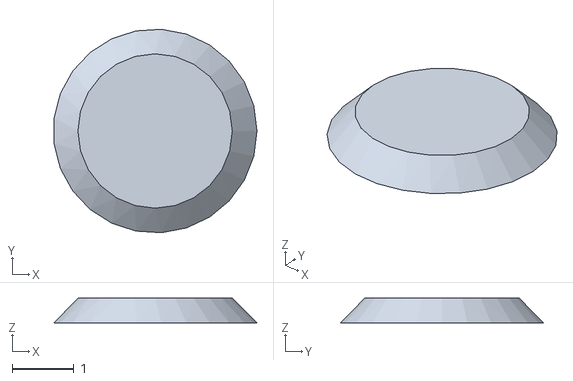
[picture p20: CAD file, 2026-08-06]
hardware/3d-models/EnclosureCover-Lemmy-LED.stl
3.29 x 3.29 x 0.4

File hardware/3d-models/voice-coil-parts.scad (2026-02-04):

// Voice Coil Actuator - 3D Printable Parts
// For Guitar Hero Bot Project
// 
// Designed to fit around Cherry MX compatible keyboard switches
// 
// Usage:
//   1. Open in OpenSCAD
//   2. Enable Customizer: View → Customizer (or View → Hide Customizer to toggle)
//   3. Select part from dropdown in "Part Selection" section
//   4. Render (F6) and Export as STL (File → Export → Export as STL)
//
// Alternative (without Customizer):
//   - Scroll to bottom of file
//   - Change PART = "assembly" to PART = "bobbin" (or housing, wire_guide, print_plate)
//
// Command line export:
//   openscad -o bobbin.stl -D 'PART="bobbin"' voice-coil-parts.scad
//   openscad -o housing.stl -D 'PART="housing"' voice-coil-parts.scad
//   openscad -o wire_guide.stl -D 'PART="wire_guide"' voice-coil-parts.scad
//
// Print settings:
//   - Layer height: 0.15-0.2mm
//   - Infill: 30-50%
//   - Material: PLA or PETG
//   - Supports: Yes for housing (magnet pockets)

// ============================================================
// CONFIGURATION PARAMETERS
// ============================================================

// Switch dimensions (Cherry MX compatible)
switch_width = 15.6;        // Switch body width
switch_depth = 15.6;        // Switch body depth  
stem_diameter = 4.0;        // MX stem cross diameter
stem_socket_dia = 4.3;      // Socket with clearance

// Magnet dimensions (N42 10x5x3mm blocks)
magnet_length = 10.0;
magnet_width = 5.0;
magnet_height = 3.0;
magnet_clearance = 0.2;     // Extra space for fit

// Steel yoke dimensions
yoke_thickness = 2.0;
yoke_width = 10.0;

// Coil dimensions
coil_wire_dia = 0.29;       // 30 AWG with enamel
coil_turns = 60;
coil_layers = 2;
coil_width = 3.0;           // Fits in magnet gap
coil_height = coil_layers * coil_wire_dia * (coil_turns/coil_layers/30);

// Air gap
air_gap = 3.5;              // Space between magnets

// General tolerances
print_tolerance = 0.2;      // General clearance for 3D printing
tight_tolerance = 0.1;      // For press fits

// Derived dimensions
housing_inner = switch_width + 2 * print_tolerance;
housing_wall = 2.0;
housing_outer = housing_inner + 2 * (magnet_width + housing_wall + air_gap/2);

// ============================================================
// HELPER MODULES
// ============================================================

// Rounded rectangle
module rounded_rect(w, d, h, r) {
    hull() {
        translate([r, r, 0]) cylinder(r=r, h=h, $fn=32);
        translate([w-r, r, 0]) cylinder(r=r, h=h, $fn=32);
        translate([r, d-r, 0]) cylinder(r=r, h=h, $fn=32);
        translate([w-r, d-r, 0]) cylinder(r=r, h=h, $fn=32);
    }
}

// Cherry MX stem cross shape (for socket)
module mx_stem_cross(height, clearance=0) {
    stem_long = 4.0 + clearance;
    stem_short = 1.2 + clearance;
    
    union() {
        // Vertical bar
        translate([-stem_short/2, -stem_long/2, 0])
            cube([stem_short, stem_long, height]);
        // Horizontal bar
        translate([-stem_long/2, -stem_short/2, 0])
            cube([stem_long, stem_short, height]);
    }
}

// ============================================================
// BOBBIN (Moving Part)
// ============================================================
// 
// The bobbin holds the voice coil and attaches to the switch stem.
// It moves up and down within the magnetic gap.
//
//              ┌─────────────────┐
//              │   Top surface   │
//              │  ┌───────────┐  │
//              │  │ Stem      │  │
//              │  │ socket    │  │
//              │  │    +      │  │
//              │  └───────────┘  │
//              │  ┌───────────┐  │
//              │  │░░░░░░░░░░░│  │ ← Coil groove
//              │  │░░░░░░░░░░░│  │
//              │  └───────────┘  │
//              └─────────────────┘

module bobbin() {
    bobbin_outer = 18;          // Outer dimension
    bobbin_inner = 10;          // Inner opening (clears switch top)
    bobbin_height = 8;          // Total height
    coil_groove_depth = 2.5;    // Depth of groove for wire
    coil_groove_width = coil_width + 0.5;  // Width with clearance
    stem_socket_depth = 4.5;    // How deep stem inserts
    wall = (bobbin_outer - bobbin_inner) / 2;
    
    difference() {
        // Main body
        translate([-bobbin_outer/2, -bobbin_outer/2, 0])
            rounded_rect(bobbin_outer, bobbin_outer, bobbin_height, 2);
        
        // Inner opening (switch clearance)
        translate([-bobbin_inner/2, -bobbin_inner/2, -1])
            cube([bobbin_inner, bobbin_inner, bobbin_height + 2]);
        
        // Coil groove (rectangular channel around perimeter)
        coil_groove_inner = bobbin_inner + 0.5;
        coil_groove_outer = bobbin_outer - 1.0;
        
        difference() {
            translate([-(coil_groove_outer)/2, -(coil_groove_outer)/2, bobbin_height - coil_groove_depth])
                cube([coil_groove_outer, coil_groove_outer, coil_groove_depth + 1]);
            
            translate([-(coil_groove_inner)/2, -(coil_groove_inner)/2, bobbin_height - coil_groove_depth - 1])
                cube([coil_groove_inner, coil_groove_inner, coil_groove_depth + 3]);
        }
        
        // Stem socket (MX cross shape)
        translate([0, 0, -1])
            mx_stem_cross(stem_socket_depth + 1, 0.3);
        
        // Wire exit slots (two opposite sides)
        wire_slot_width = 2;
        wire_slot_depth = 3;
        translate([-bobbin_outer/2 - 1, -wire_slot_width/2, bobbin_height - wire_slot_depth])
            cube([wall + 2, wire_slot_width, wire_slot_depth + 1]);
        translate([bobbin_outer/2 - wall - 1, -wire_slot_width/2, bobbin_height - wire_slot_depth])
            cube([wall + 2, wire_slot_width, wire_slot_depth + 1]);
    }
    
    // Add stem alignment guides
    guide_height = 2;
    guide_width = 1.5;
    for (angle = [0, 90, 180, 270]) {
        rotate([0, 0, angle])
            translate([stem_socket_dia/2 + 0.5, -guide_width/2, 0])
                cube([1, guide_width, guide_height]);
    }
}

// ============================================================
// HOUSING (Fixed Part)
// ============================================================
//
// The housing holds the magnets and steel yokes, and mounts
// around the keyboard switch.
//
//    ┌─────────────────────────────┐
//    │ ┌───┐               ┌───┐   │
//    │ │Mag│    ┌─────┐    │Mag│   │ ← Magnet pockets
//    │ │   │    │     │    │   │   │
//    │ └───┘    │     │    └───┘   │
//    │          │Swtch│            │ ← Switch opening
//    │ ┌───┐    │     │    ┌───┐   │
//    │ │Mag│    │     │    │Mag│   │
//    │ │   │    └─────┘    │   │   │
//    │ └───┘               └───┘   │
//    │ ════════════════════════    │ ← Yoke slot
//    └─────────────────────────────┘
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

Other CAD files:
hardware/3d-models/Enclosure-Lemmy.stl
hardware/3d-models/Fretboard-Spacer.stl
hardware/3d-models/MarvinMountSeparatorClick.stl
hardware/3d-models/LemmyServos.stl
hardware/3d-models/DisplayMountFoot.stl
hardware/3d-models/Enclosure-Fauxmote.stl
hardware/3d-models/Faceplate.stl
hardware/3d-models/Fretboard-Cover.stl
hardware/3d-models/LemmyMountBottom.stl
hardware/3d-models/MarvinFaceplate.stl
hardware/3d-models/MarvinMount.stl
hardware/3d-models/MarvinMountSeparator.stl
hardware/3d-models/PlywoodPanel.dxf
hardware/3d-models/voice-coil-parts.stl

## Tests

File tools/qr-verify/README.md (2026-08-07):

# qr-verify

Decode-checks the QR codes on marvin's **System Info** detail screen.

The QRs are not stored anywhere — they are encoded on the panel at screen setup from the
URLs in the `NODE` table
(`firmware/marvin/default/src/ui/screens/system/screen_system.c`). So there is no asset
to inspect: this tool compiles the firmware's own rasterizer for the host, renders every
URL in that table, and decodes the result with an independent decoder.

```bash
cd tools/qr-verify
uv run verify.py                  # verify every URL in the NODE table
uv run verify.py --png data/tiles # also dump the tiles as PNGs to look at
```

Expected output:

```
8 QR URLs in the NODE table (5 unique)

ok   marvin       50B  164px  https://www.microchip.com/en-us/product/SAM9X75D2G
...
all 8 QR tiles decode back to their URL
```

## What it actually links

`qr_dump.c` (host-only) plus two unmodified firmware sources:

- `firmware/marvin/default/src/ui/gfx/qr_raster.c` — the rasterizer, deliberately free
  of Legato and Harmony dependencies so it compiles on the host
- `firmware/marvin/default/src/third_party/qrcodegen/qrcodegen.c` — vendored encoder

`ui/qr_art.c` is *not* linked: it is the Legato/DDR cache around the rasterizer, and has
no pixel logic of its own to get wrong.

## What it checks

- the tile decodes, and the decoded text equals the URL character for character
- the tile is exactly 164x164 — the size the screen's layout constants are derived from
- every pixel is pure black or pure white (a QR is not antialiased)
- the 4-module quiet zone is genuinely blank
- the URL still fits the pinned QR version, cross-checked against an independent encoder

That covers the ways a rasterizer goes wrong — stride, transposition, inversion, a quiet
zone eaten by an off-by-one — none of which look wrong to a human glancing at a QR.

The URL list is scraped from `screen_system.c`, not duplicated here, so a URL added to
the table is verified without touching this tool. It hard-fails if the number of
`.qr_url` initializers does not match the number of `.name` entries, since that means
the scrape has silently lost track of which URL belongs to which card.

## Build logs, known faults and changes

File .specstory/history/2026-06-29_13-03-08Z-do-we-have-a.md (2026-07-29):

<!-- Generated by SpecStory, Markdown v2.1.0 -->

# 2026-06-29 13:03:08Z

<!-- Claude Code Session 376b9b51-cedb-4095-acdf-56ad1b3149c2 (2026-06-29 13:03:08Z) -->

_**User (2026-06-29 13:03:08Z)**_

do we have a script or something to convert splash screen jpg to RAW?

---

_**Agent (claude-opus-4-8 2026-06-29 13:04:33Z)**_

<tool-use data-tool-type="shell" data-tool-name="Bash"><details>
<summary>Tool use: **Bash**</summary>
Find splash/raw conversion scripts in marvin

`grep -rl --include=*.{py,sh,js} -iE "raw|splash|bgrx|rgb565|jpg|jpeg" firmware/marvin 2>/dev/null | grep -ivE "config/default|node_modules" | head -50`

```text
(eval):1: no matches found: --include=*.py
```
</details></tool-use>

_**Agent (claude-opus-4-8 2026-06-29 13:04:37Z)**_

<tool-use data-tool-type="shell" data-tool-name="Bash"><details>
<summary>Tool use: **Bash**</summary>
Find splash/raw files

`find . -path ./node_modules -prune -o \( -iname "*splash*" -o -iname "*2raw*" -o -iname "*toraw*" -o -iname "*tobgrx*" \) -print 2>/dev/null | grep -vi config/default | head -50`

```text
./firmware/marvin/data/ui/splash.raw
./firmware/marvin/data/ui/splash.jpg
./firmware/marvin/default/src/ui/screens/splash
./firmware/marvin/default/src/ui/screens/splash/splash.c
./firmware/marvin/default/src/ui/screens/splash/splash.h
./firmware/marvin/_build/marvin/default/.cache/clangd/index/splash.h.022246333233151F.idx
./firmware/marvin/_build/marvin/default/.cache/clangd/index/splash.c.6111581EDCE1D44B.idx
./firmware/marvin/_build/marvin/default/.cache/clangd/index/le_gen_screen_Splash.h.3D599B2DFFE477A7.idx
./firmware/marvin/_build/marvin/default/.cache/clangd/index/le_gen_screen_Splash.c.19DA704FA578FC0E.idx
./firmware/marvin/_build/marvin/default/.cache/clangd/index/screen_splash.c.6BD5A51F19CBFF63.idx
./firmware/marvin/_build/marvin/default/.cache/clangd/index/screen_splash.h.5088779F35C418A8.idx
./firmware/marvin/_build/marvin/default/CMakeFiles/marvin_default_default_XC32_compile.dir/Users/gregmrozek/Projects/microchip/guitar-pic/firmware/marvin/default/src/ui/screens/splash
./firmware/marvin/_build/marvin/default/CMakeFiles/marvin_default_default_XC32_compile.dir/Users/gregmrozek/Projects/microchip/guitar-pic/firmware/marvin/default/src/ui/screens/splash/splash.c.o
```
</details></tool-use>

_**Agent (claude-opus-4-8 2026-06-29 13:04:44Z)**_

<tool-use data-tool-type="shell" data-tool-name="Bash"><details>
<summary>Tool use: **Bash**</summary>
List ui data dir and scripts

`ls -la firmware/marvin/data/ui/ 2>/dev/null; echo "---scripts---"; find firmware/marvin -name "*.py" -o -name "*.sh" 2>/dev/null | grep -vi config/default | grep -vi _build | head -40`

```text
total 8688
drwxr-xr-x@ 4 gregmrozek  staff      128 Jun 29 08:02 .
drwxr-xr-x@ 6 gregmrozek  staff      192 Jun 27 10:19 ..
-rw-r--r--@ 1 gregmrozek  staff   350453 Jun 29 08:01 splash.jpg
-rw-r--r--@ 1 gregmrozek  staff  4096000 Jun 27 10:19 splash.raw
---scripts---
firmware/marvin/openocd/make-sdcard.sh
firmware/marvin/openocd/nand_console.py
firmware/marvin/openocd/erase-nand.sh
firmware/marvin/openocd/program-qspi.sh
firmware/marvin/openocd/program-nand.sh
firmware/marvin/openocd/load-ram.sh
firmware/marvin/openocd/qspi_console.py
firmware/marvin/binaries/make-pmecchead.sh
firmware/marvin/ftdi/flash-eeprom.sh
```
</details></tool-use>

_**Agent (claude-opus-4-8 2026-06-29 13:04:45Z)**_

<tool-use data-tool-type="shell" data-tool-name="Bash"><details>
<summary>Tool use: **Bash**</summary>
Search docs/tools for splash conversion

`grep -rsil "splash.raw\|splash.jpg\|BGRX\|bgrx\|convert" firmware/marvin/docs firmware/marvin/tools firmware/marvin/scripts 2>/dev/null | head; echo "---"; grep -rsn "splash" firmware/marvin/docs/journal.md 2>/dev/null | head -30`

```text
firmware/marvin/docs/ui_compositor.md
firmware/marvin/docs/journal.md
firmware/marvin/docs/journal-archive.md
firmware/marvin/docs/yellow_tinge.md
firmware/marvin/docs/capture_pipeline.md
firmware/marvin/docs/spec.md
---
firmware/marvin/docs/journal.md:36:| 2026-06-28 | **QSPI 8 MiB partition map locked — `flash/qspi_layout.h` is the single source of truth.** Splash blob `0x000000` (4 MiB) · UI assets `0x400000` (~3.98 MiB) · Settings ring `0x7FC000` (16 KiB / 4 sectors). All boundaries 4 KiB sector-aligned; contiguous, no gaps/overlaps. Splash at offset 0 (raw pre-decoded framebuffer; 4 MiB holds full-panel RGBA8888 = 3.91 MiB, or an RGB565 splash uses ~1.95 MiB — the reservation keeps both open, format decided when the loader is built). Read-mostly bulk grows upward; the small, frequently-erased settings ring sits at the very top as a stable anchor, **wear-isolated** from the bulk. Settings get 4 sectors (2× the 2-sector ping-pong minimum) for ring headroom. UI assets indexed by **compile-time offsets** for now (flashed with firmware); a manifest sector / littlefs can be carved from the front of the assets region later if assets must update independently. | One header (`qspi_layout.h`) means consumers and the `qspi` dev tools share offsets — no drift. Settings-at-top isolates erase wear and gives a fixed anchor independent of how the bulk grows. **Dev-tool caveat:** `qspi` smoke (last sector `0x7FF000`) and `qspi verify` (top-down) write into the settings region — destructive to it, but the ring-log's CRC-fallback-to-defaults makes that non-fatal (settings just reinitialize). Run heavy `qspi verify` before the settings store is populated, or accept a settings reset. | 
firmware/marvin/docs/journal.md:37:| 2026-06-28 | **QSPI read throughput — the serial clock (GCLK = 2×QSCK) was the lever, not per-access overhead. At 200 MHz GCLK (MCC max → 100 MHz QSCK), XDMAC mem2mem reads hit 18.2 MB/s → ~225 ms for a 4 MB splash, ~3× faster than SD (~750 ms). Read integrity verified at volume. Splash → QSPI via XDMAC mem2mem is GO.** Bench (`qspi bench`, `flash/qspi_smoke.c`) at 50 MHz GCLK → 25 MHz QSCK showed ~5 MB/s and I wrongly concluded "overhead-bound, clock maxed." Greg caught the datasheet note **GCLK must = 2×QSCK** and raised GCLK 50→200 MHz; everything scaled ~linearly (DRV_SST26_Read 4.6→14.8, XDMAC mem2mem 4.9→18.2 MB/s; the raw libc `memcpy` path stays ~2.5 — it is just bad on this region, ignore it). Read path = **XDMAC channel 1 mem2mem from `QSPIMEM_ADDR` (0x60000000)** — ch0 is the ISC histogram DMA, and the PLIB only tracks ch0, so we program ch1's registers directly. Integrity confirmed by `qspi verify 1024 4`: 1 MiB × 4 passes via **both** the driver and XDMAC, **0 mismatches** at 100 MHz, with a position-dependent pattern (catches misaddressing, not just stuck bits). **Two dead ends ruled out:** (a) making the QSPI window **cacheable** in the MMU **hangs** — cache-linefill bursts aren't serviced by the SMM slave (back out; XDMAC bypasses the MMU so it's unaffected); (b) **continuous-read mode (CRM)** only trims the instruction byte on *non-sequential* access, so it does nothing for bulk sequential reads. SMM tops out ~36% of the 50 MB/s theoretical (re-frames per access); the only path to ~50 MB/s (~80 ms) is the QSPI's RX-triggered streaming read — deferred as a mini-project, not worth it over 225 ms. | The clock fix flipped the verdict: at 25 MHz QSCK QSPI-SMM (~5 MB/s, ~800 ms) was *worse* than SD's read; at 100 MHz QSCK (18.2 MB/s) it clearly wins. 100 MHz is within the SST26's 104 MHz rating and proved data-clean at volume, so no DLL/read-training needed at this rate. 200 MHz GCLK is an MCC clock-config change (lives in MCC config → survives regen). **Gotcha for any raw SMM read (memcpy/DMA, bypassing `DRV_SST26_Read`):** the read frame must be closed with `QSPI_CR.LASTXFER` + wait-CSRA or the next QSPI command hangs with CS still asserted — the driver does this internally; raw paths must call an equivalent (`qspi_end_smm_read()` in the bench). Splash framebuffer is in `.region_nocache` (strongly-ordered 0x20000000) but XDMAC writes bypass the MMU, so DMA→framebuffer is unaffected. | 
firmware/marvin/docs/journal.md:38:| 2026-06-28 | **Config/operator settings (backlight %, mode toggles, calibration) persist to the onboard QSPI NOR (`SST26VF064BA`, 8 MB / 64 Mbit SQI) via flash EEPROM-emulation — a small wear-leveled ring-log, NOT a filesystem. No board EEPROM exists, so QSPI is the only non-volatile small-state store.** Reserve ≥2× 4 KB sectors as a ping-pong region: a save appends a `{seq, settings_t, CRC}` record to the next free slot in the active sector (page-program, *no erase*); when full, write the latest record into the pre-erased partner sector then erase the full one. Boot picks the highest-`seq` record with a valid CRC; a partial trailing record (power lost mid-write) fails CRC and falls back to the prior good record → **power-fail safe by construction**, no torn settings. This supersedes the spec §4.6.2/§4.7 plan to keep all config in `/marvin/config.json` on the SD card: operator/UI prefs must persist and load **even with no SD card inserted** (the SD is removable, QSPI is always present). Session/recording config that travels with the data can stay on SD. **Splash, when/if it moves to QSPI, is stored as a raw pre-decoded framebuffer blob at a fixed offset — also no filesystem.** | NOR semantics drive the design: bits only clear 1→0 on program; setting a bit back to 1 requires erasing the whole 4 KB sector, so "update a value" = erase+rewrite 4 KB. FAT makes that worse (every file write also rewrites FAT/dir sectors → write amplification) and FatFs is *not* power-loss-atomic → a mid-write power cut can corrupt the FAT itself, not just the value. The ring-log avoids both: erases are rare (~one per N saves, N = slots/sector) and alternate across sectors, giving effectively unlimited endurance for human-driven settings against the part's ~100k cycles/sector; atomicity is the seq+CRC scan. littlefs (Harmony File System can back it) is the fallback **only** if settings grow into many named, workstation-mountable keys — overkill for a handful of scalars. **Raw-only splash:** the seed `splash.jpg` carries ~2 s of on-target JPEG decode, which dwarfs any bringup savings, so a JPEG-on-QSPI splash would be *slower* than today's SD path — only a raw blob streamed straight to the framebuffer (no decode, no FS mount, no FTL — NOR has none) realizes QSPI's sub-ms bringup vs. SD's ~350 ms `ACMD41` power-up handshake. | 
firmware/marvin/docs/journal.md:39:| 2026-06-26 | **Boot splash = full-screen SD JPEG shown on BASE before the backlight comes on; first real use of the compositor "replace" verb. Code-complete, pending hardware test.** The `Splash` MGS screen (`le_gen_screen_Splash.c`: full-screen solid-fill `Splash_Panel_0`) is the base — kept for the "every base view has an MGS component" convention; `ui/screens/splash/screen_splash.c` adds one `leImageWidget` onto that panel in code (the photo is a runtime SD asset, can't be an MGS asset). A new boot loader task (`ui/loader.c`) mounts the card, reads `/<card>/ui/splash.jpg` into a static buffer, builds a runtime `leImage` (format JPEG) + sets it on the widget, then `UiManager_EnableBacklight()` (backlight control moved out of `video` into `ui_manager` — the UI owns the display; it was only in `video` for historical reasons), and reveals the dashboard + brings video up. **Per-screen pre-rendered persistent canvases** (revised within-session — see bring-up #1/#2): every screen is MGS-**persistent** (built once, never torn down) and owns its own canvas/Legato-layer/HW-layer — Dashboard 0/0/BASE (RGB565), Nav 1/1/OVR1 (RGB565), Splash 2/2/OVR2 (RGBA8888, full-screen, topmost). The splash is drawn over the dashboard on OVR2; the heavy Dashboard paints **behind** it and is revealed (hide OVR2) already complete. **Off-screen paint:** all screens are built pre-scheduler (no concurrency); the normal Legato render task paints them once the scheduler is up, and the loader simply pends on the public `leRenderer_IsIdle()` before lighting the panel (no scheduler hacking — see bring-up #4/#5 for the suspend/pump dead-end). RGB888 splash via the canvas's own 32bpp mode (the canvas framework sets the HW-layer color mode from `pixelBuffer.mode`); the RGB565↔8888 BASE-swap of the first cut is gone. Missing/oversized/no-card → the panel's solid fill is the fallback. Seed `data/ui/splash.jpg` (placeholder). Design in [`ui_compositor.md`](ui_compositor.md) §12–§13. | "Turn on the display" = enable the backlight (XLCDC scans continuously from `SYS_Initialize`), so gating the backlight on splash-ready is the whole mechanism. First on-hardware run showed reveal-before-paint noise (screens shown mid-paint over uninitialized DRAM); the fix is to paint each screen to completion off-screen, then reveal — the §1 compositor ideal, enabled by persistent screens + pumping the renderer to idle off-screen. JPEG over BMP/RAW: BMP isn't Legato-decodable (only RAW/JPEG/PNG), so it would mean a custom parser + bypassing the `leImageWidget` path and would prove nothing reusable; JPEG reuses Legato's enabled decoder and **is** the album-art pre-load path. RGB888-without-hoops confirmed in `gfx_canvas.c` (per-canvas mode auto-configures the XLCDC layer), so the splash gets full color depth while the steady-state dashboard stays RGB565 to save DDR bandwidth; the 32bpp splash buffer doubles as future album-art decode scratch. Splash kept as an MGS shell (Greg's call) for base-view uniformity even though its only real content is the loaded image; the image widget is code-added since it's runtime data. Loader is a task (not `APP_Initialize`) because SD mount + FatFs + decode block on I/O and need the scheduler. Known one-time-boot roughness (hard splash→dashboard cut; fixed backlight settle vs a real paint-complete signal; baseline-JPEG-only) tracked in §10/§12. | 
firmware/marvin/docs/journal.md:135:- **QSPI NOR (`SST26VF064BA`, 8 MB) storage tiering — driver bring-up DONE on hardware (2026-06-28), settings approach settled, splash + assets open.** QSPI PLIB + `DRV_SST26` (SQI) bring-up is **confirmed on hardware** via the `qspi` console smoke test (session log 2026-06-28): JEDEC `BF 26 43`, geometry 8 MiB (read 1×8388608, write page 256×32768, erase 4096×2048), and erase/page-program/read-back all verify clean. So these are now **answered**: the driver's `ResetFlash→EnableQuadIO→UnlockFlash` handles the global block-protection unlock automatically (erase/write work with no manual `ULBPR`), and `DRV_SST26_Tasks` pumping is a non-issue (no poll timeout). Settings → QSPI EEPROM-emulation is decided, and **read throughput is now characterized and integrity-verified** (2026-06-28 decision log + session log): GCLK=200 MHz → 100 MHz QSCK, **XDMAC mem2mem = 18.2 MB/s → ~225 ms for a 4 MB splash, ~3× faster than SD**; `qspi verify` clean at 1 MiB × 4 passes on both driver and XDMAC paths. So splash-on-QSPI is **viable and decided GO** via XDMAC ch1 mem2mem (cacheable-MMU and CRM ruled out; RX-triggered streaming → ~80 ms deferred as a mini-project). **Partition map is locked** (`flash/qspi_layout.h`, decision log 2026-06-28): splash `0x000000` (4 MiB) · assets `0x400000` (~3.98 MiB) · settings `0x7FC000` (16 KiB). **Both runtime consumers are built + confirmed on hardware (2026-06-28):** (1) the **settings ring-log** (`flash/settings.c`, EEPROM-emulation; backlight persists across power-cycle); (2) the **splash read** (`splash.c` reads `QSPI_SPLASH_OFFSET` via `DRV_SST26_Read` — **263 ms, splash shows with the SD card removed**). Host→QSPI **provisioning** is via u-boot `sf` over JTAG (`openocd/program-qspi.*` + `qspi_console.py`) — no SD card-swapping for assets. The splash read uses `DRV_SST26_Read` not XDMAC: at 263 ms it's already ~as fast as XDMAC (~225 ms), so XDMAC-for-splash isn't worth the ~40 ms. **Still open:** the **assets read-side** consumer (icons/fonts/album-art templates from `QSPI_ASSETS_OFFSET`) is unbuilt — the provisioning tool already writes that region. **at91bootstrap lives on NAND and does not touch the QSPI — we own the full 8 MB at the app level (QSPI splash is firmware-only, no bootstrap change).** NAND (`MX30LF4G28AD`, 512 MB) holds the app image (at91bootstrap copies it to DDR at boot); SD card stays for recordings/keyframes/results/bulk art. **Note:** the 200 MHz GCLK is an MCC clock-config change — verify it survives/needs-reapply on MCC regen, and re-run `qspi verify` after any QSPI MCC regen.
firmware/marvin/docs/journal.md:137:  **Load-time estimate vs. SD (measured 2026-06-28):** SD does the 4 MB raw RGBA8888 splash (1280×800×4 = 4.1 MB) in **~300 ms bringup + ~450 ms read** (~9 MB/s effective). QSPI eliminates the bringup (~1–5 ms) and reads faster: SST26 in SQI quad gives ~45 MB/s at the 104 MHz part max (~90 ms), down to ~25 MB/s if the controller caps SCK near 50 MHz (~165 ms) — so **~90–165 ms read vs. SD's 450 ms (~3–5× on the read alone), ~95–170 ms total vs. ~750 ms (~4–7× end-to-end)**. Assumes DMA from the memory-mapped region (a CPU `memcpy` is slower per-access). Endgame for a static splash: if the LCDC can scan straight out of memory-mapped QSPI (XIP), the DDR copy is skipped and load time → ~0 (at the cost of holding the QSPI bus during scanout). RGB565 (2 MB) halves the read numbers. Confirm the actual SCK rate on hardware before trusting these.
firmware/marvin/docs/journal.md:212:The splash now lives in QSPI NOR, not on the SD card — **confirmed booting with no SD inserted**, splash up in **263 ms** (`SPLASH: 4096000 B from QSPI in 263 ms`).
firmware/marvin/docs/journal.md:214:- **Read side (`ui/screens/splash/splash.c`):** `Splash_Load()` dropped the SD/FatFs path (`Storage_Mount` + `SYS_FS_*` + chunked file read) and now does `DRV_SST26_Open` → `DRV_SST26_Read(s_fb, 4,096,000, QSPI_SPLASH_OFFSET)` → `Close`, falling back to the opaque fill only on a flash error. This also removes the SD bring-up (~300 ms) from the splash path entirely — SD still mounts later for catalog/recordings. `DRV_SST26_Read` (CPU) not XDMAC: 263 ms is ~as fast as XDMAC (~225 ms) since the QSPI read dominates and the strongly-ordered framebuffer writes overlap, so XDMAC-for-splash is dropped (~40 ms, not worth it).
firmware/marvin/docs/journal.md:215:- **Provisioning (`openocd/program-qspi.{sh,cfg,md}`, `qspi_console.py`):** host→QSPI over JTAG, mirroring the NAND flow — stage an init-and-stop at91bootstrap (DDR up) + a u-boot SF flasher + the blob into DDR, then drive the u-boot console `sf probe`/`erase`/`write`/verify. `splash` / `assets` / `raw` targets (settings region guarded); `shell` mode stages u-boot only for interactive `sf` poking. The **committed NAND-flasher u-boot already has SF** (`sf probe` detects the SST26) — it's the default `UBOOT_BIN`, so no qspiflash build was needed. Bugs found + fixed on first run: u-boot parses args as **hex** (pass lengths in hex), `sf erase` needs **64 KiB-aligned** length for this part (`ERROR -22` otherwise), and the verify must key on `: OK` / absence of `!=` (terse u-boot output substring-matched `Erased`/`were the same` even on failure). Heartbeat dots added — the multi-MB erase/write is silent for ~10-25 s (expected, one-time).
firmware/marvin/docs/journal.md:216:- **Boot chain reminder:** the `NAND: ... Copy 0x100000 from 0x40000 to 0x23f00000` lines at boot are at91bootstrap loading the marvin **app** from NAND — normal, unrelated to the splash (which the `from QSPI` line proves comes from QSPI).
firmware/marvin/docs/journal.md:220:`flash/settings.{c,h}` implements the persistent operator/UI settings store over the `QSPI_SETTINGS_*` region (16 KiB / 4 sectors → 64 page-slots). Each record is a 256-byte page slot `{magic, seq, settings_t, crc32}` (CRC over magic..data). Boot scans all 64 slots and picks the highest-`seq` CRC-valid record (else compiled defaults); `Settings_Save()` appends to the next slot and erases a sector only when crossing into it — always ahead of the live record, so it's **power-fail safe** (a torn write fails CRC → previous record wins) and **wear-rotated** (~1 erase per 16 saves, alternating sectors). Bitwise CRC-32, static scratch buffers, bounded synchronous polling (safe pre-scheduler). Payload `settings_t` = `{version, backlight_pct, reserved0}`, extensible via `version`. `settings` console command: `dump`/`save`/`wipe`/`stress [n]`/`backlight <pct>` (applies live + persists). **`settings stress` PASS at 200 and 1000 saves** — wipes, saves N (recomputable values), then reloads from flash and verifies the highest-`seq` record matches the last write; confirms ring wrap + sector erase never clobber the live record. Note: `qspi` smoke/`verify` write the same region (CRC-fallback-to-defaults makes that non-fatal). **Wired into boot (confirmed on hardware — backlight survives power-cycle):** `enable_backlight()` lights the panel at `Settings_Get()->backlight_pct` (lazy-loads the ring; compiled default 50% if no record — the hardcoded `BACKLIGHT_DEFAULT_PCT` in `ui_manager` is removed), and the `backlight <pct>` console command applies live + persists. First QSPI consumer is live; splash-blob + DMA load is the remaining one.
firmware/marvin/docs/journal.md:232:**Net:** splash → QSPI via XDMAC mem2mem (~225 ms vs SD ~750 ms) is viable and proven; settings → QSPI EEPROM-emulation unchanged. Both QSPI uses green. Next: build the two consumers (settings ring-log; raw splash blob + DMA load) and lay out the 8 MB partition map.
firmware/marvin/docs/journal.md:244:Confirms: pins (PB19 SCK / PB20 CS / PB21–24 IO0–3), quad-mode entry, 8 MiB geometry, and — the usual SST26 trap — the driver's init (`ResetFlash→EnableQuadIO→UnlockFlash`) clears the power-on global block protection automatically, so erase/program work with no manual `ULBPR`. No `DRV_SST26_Tasks`-pumping timeout, so that open concern is moot. The smoke test writes only the **last** erase block (`0x7FF000`) to keep low offsets free for the splash/assets. **Stack added:** QSPI PLIB → `DRV_SST26` only — **no Memory Driver, no File System** (raw blobs + EEPROM-emulation talk to `DRV_SST26` directly). Next: push SCK toward 104 MHz + enable DMA, then build the two real consumers (raw splash blob read, EEPROM-emulation ring-log for settings). Detail + load-time estimate in the QSPI open-questions entry.
firmware/marvin/docs/journal.md:248:MCC reconfigured PC18 from a plain GPIO (`AC69T88A_BACKLIGHT_EN`) to a **PWM output** (PWM channel 0: MCK/1024, left-aligned, CPRD=256). The old `AC69T88A_BACKLIGHT_EN_Set()` macro is gone, so `ui_manager`'s `enable_backlight()` was updated to drive the PWM instead. New `set_backlight(pct)` helper: reads the channel period at runtime and sets duty = period·pct/100 via `PWM_ChannelDutySet` (writes CDTY while stopped, the update reg once running — valid both at boot and at runtime); `enable_backlight()` sets the default then `PWM_ChannelsStart`. Default **50%** (`BACKLIGHT_DEFAULT_PCT`); 50% = period/2 is polarity-independent. Duty is set before the channel starts, so it comes up straight at 50% with no transient. `PWM_Initialize()` already runs at initialization.c:443; the channel is stopped (no output) until `enable_backlight`, preserving "dark until splash". Confirmed working on hardware (50% at boot).
firmware/marvin/docs/journal.md:252:**Duty direction (SAM PWM gotcha):** SAM PWM `CDTY` is the time spent at the **`CPOL` level**, not absolute high-time. With `CPOL_LOW` (which we keep — it idles the pin low = dark when the channel is stopped, no pre-splash glare), `CDTY` is the *low* time, so raw `CDTY=0` = full bright and `CDTY=CPRD` = off — inverted from a typical "duty=on-time" PWM. `UiManager_SetBacklight` therefore sets `CDTY = period·(100−pct)/100`, so the API is intuitive (`backlight 0` = off, `backlight 100` = full bright; 50% is symmetric, which masked the initial wrong-direction bug). Can't get both idle-low *and* raw-`CDTY`-intuitive on this peripheral (both tied to `CPOL`) without output-override — not worth it; the software inversion is the clean layer. Confirmed on hardware.
firmware/marvin/docs/journal.md:254:### 2026-06-27 — UI boot rewrite: splash module + ui_manager orchestrator, loader retired (confirmed on hardware)
firmware/marvin/docs/journal.md:258:**New module `screens/splash/splash.{c,h}` — self-contained, Legato-independent.** Owns its RGBA8888 framebuffer + canvas surface; `Splash_Load()` reads `/ui/splash.raw` straight into it (or fills opaque-black fallback), plus `Splash_InitSurface()` / `Splash_CanvasId()`. No layer choice, no Legato, no backlight — just "load my pixels."
firmware/marvin/docs/journal.md:260:**`ui_manager` rewritten as orchestrator + compositor.** Owns the canvas-id + HW-layer constants (single source of truth in `ui_manager.h`), a screen registry (`{init, get_root, host, canvas}` rows — Dashboard, Nav; add a screen = one row), the boot task, layer assignment, and the backlight. Public API shrank to `UiManager_Initialize()` (pre-scheduler: assign surfaces + create boot task) and `UiManager_SetSplashShownCallback()`. Boot task: **Phase 1** `Splash_Load` → bind splash canvas to OVR1 + backlight (Legato-independent, fast) → fire splash-shown callback; **Phase 2** (guarded) `init_screens()` (each `screenInit_*` builds into Legato layer 0, then detached so the next can) → host dashboard + nav → bind dashboard to BASE → paint behind splash → after `SPLASH_MIN_MS` hide splash and give the nav OVR1.
firmware/marvin/docs/journal.md:262:**Layer assignment is now ui_manager policy, never screen-owned.** `bind_canvas(canvas, hw, mode, show)` is the one place a canvas meets a layer; it pokes the layer's RGBMODE to match the canvas (the XLCDC driver never writes it), so the old "restore OVR1→RGB565 for nav" special case is gone. Splash holds OVR1 during boot; nav is bound to OVR1 only at reveal (after the splash vacates it — never shared live). `screen_nav.c`: dropped the hardcoded `gfxcSetLayer(NAV_CANVAS, HW_OVR1)` and local `HW_OVR1`/`NAV_CANVAS` (now `CANVAS_NAV` from `ui_manager.h`); `Navigation_OnShow` is the layer-agnostic host hook. (Memory `marvin-canvas-layer-binding` strengthened — Greg corrected this repeatedly.)
firmware/marvin/docs/journal.md:264:**Services start at splash-shown, in parallel with screen painting.** `app.c` registers `app_on_splash_shown` (→ `App_StartServices()` + camera go-live; `VIDEO_WIN_*` moved here from loader), fired by the boot task the instant the splash is up, so everything's warm at reveal. `Loader_Start` dropped from `APP_Initialize`; `loader.{c,h}` deleted (− user.cmake), `splash.c` added.
firmware/marvin/docs/journal.md:266:**Concurrency:** Phase 2 runs post-scheduler, so the root-list mutations (`leAddRootWidget`/`leRemoveRootWidget` — no Legato locking) are wrapped in `scene_edit_begin/end` which suspend `LEGATO_Tasks` + `SYS_INPUT_Tasks` (handles by name; NULL → unguarded + warn). Safe because at guard time no app roots are attached (splash is pure scanout), so Legato is idle (`Legato_Initialize` ran pre-scheduler at initialization.c:492, independent of the task). `GFX_CANVAS_Tasks` left running.
firmware/marvin/docs/journal.md:268:**Confirmed on hardware:** splash comes up as before, dashboard reveals correctly, nav works — the rewrite is behavior-preserving. Boot-task stack is 2048 words (screens used to build on the SYS_Initialize stack); no overflow observed.
firmware/marvin/docs/journal.md:279:Moved the splash framebuffer from OVR2 to OVR1 so the topmost overlay (OVR2) is free to draw an overlay over the splash later (e.g. a loading/progress bar). Reminder recorded: canvases don't own HW layers — bind at display time (see memory `marvin-canvas-layer-binding`).
firmware/marvin/docs/journal.md:281:- Splash and nav now both use **OVR1**, but never shown together (splash during boot → hidden at reveal; nav only opens post-reveal). The splash's OVR1 bind is sequenced **after** `screenShow_Navigation` so it's the binding OVR1 holds at boot; the nav reclaims OVR1 when first opened.
firmware/marvin/docs/journal.md:282:- Color-mode handling: splash pokes OVR1 → RGBA8888 (the XLCDC driver never writes RGBMODE itself); `UiManager_RevealDashboard` pokes OVR1 back → RGB565 for the (RGB565) nav after hiding the splash.
firmware/marvin/docs/journal.md:285:### 2026-06-27 — Boot-timing arc DONE: splash visible ~785 ms (was ~4.2–5 s)
firmware/marvin/docs/journal.md:287:Confirmed on hardware: image shows correctly via direct OVR2 scanout, `mount + read` **785 ms** (mount 330 + read 446 of 4 MB), and that's the whole splash cost — no separate paint window. Splash-visible ~5 s → **~0.8 s**.
firmware/marvin/docs/journal.md:290:1. **Splash-first reveal** — light the panel when the splash is ready, not after the dashboard paints (it paints behind, during the hold).
firmware/marvin/docs/journal.md:294:5. **RAW splash → direct framebuffer** — the ~1.77 s software JPEG decode (then a 1.46 s nocache double-blit via Legato) replaced by reading `splash.raw` straight into the OVR2 scanout buffer. Splash paint cost → ~0.
firmware/marvin/docs/journal.md:296:Cleanup: removed the `util/boot_profile.{c,h}` per-task CPU profiler + its marks (diagnostic scaffolding, job done) once the arc closed. Kept the two cheap one-liners that are useful telemetry if boot ever regresses: `STG: mounted (… ms)` (storage.c) and `LOADER: splash … read in … ms` (loader.c). Re-adding the profiler is documented in this section's entries if needed.
```
</details></tool-use>

_**Agent (claude-opus-4-8 2026-06-29 13:04:50Z)**_

<tool-use data-tool-type="shell" data-tool-name="Bash"><details>
<summary>Tool use: **Bash**</summary>
Search repo-wide for raw conversion scripts

`grep -rsilE "splash\.raw|RGBA8888|tobytes|BGRX|\.raw" --include=*.py --include=*.sh --include=*.js . 2>/dev/null | grep -vE "_build|node_modules|config/default|\.cache" | head -20`

```text
(eval):1: no matches found: --include=*.py
```
</details></tool-use>

_**Agent (claude-opus-4-8 2026-06-29 13:04:54Z)**_

<tool-use data-tool-type="shell" data-tool-name="Bash"><details>
<summary>Tool use: **Bash**</summary>
Search repo-wide for raw conversion references

`grep -rsilE "splash\.raw|RGBA8888|tobytes|\.raw|Pillow|from PIL" . 2>/dev/null | grep -vE "_build|node_modules|config/default|\.cache|\.git/|\.specstory" | head -30`

```text
firmware/marvin/openocd/program-qspi.sh
firmware/marvin/openocd/program-qspi.md
firmware/marvin/openocd/program-qspi.cfg
firmware/marvin/default/src/ui/ui_manager.c
firmware/marvin/default/src/ui/screens/splash/splash.h
firmware/marvin/default/src/flash/qspi_layout.h
firmware/marvin/default/src/flash/qspi_smoke.c
firmware/marvin/default/src/detector/cv_marvin_v1.c
firmware/marvin/docs/journal.md
firmware/marvin/docs/ui_compositor.md
firmware/marvin/docs/spec.md
tools/fetch_gh3_cover_art.py
tools/fret-tuner/server.py
tools/gameplay/pyproject.toml
tools/gameplay/gameplay/perturb.py
tools/gameplay/uv.lock
tools/gameplay/tests/test_firmware_classify.py
tools/marvin-perf/uv.lock
tools/gameplay/gameplay/fingerprint.py
tools/marvin-perf/tests/test_decode.py
tools/marvin-perf/marvin_perf/capture.py
tools/marvin-perf/pyproject.toml
tools/marvin-perf/fretboard_rate.py
tools/fret-tuner/camera.py
tools/marvin-perf/tests/test_snapshot.py
tools/marvin-perf/marvin_perf/web/__init__.py
tools/gameplay/gameplay/corpus.py
tools/edge-ai/uv.lock
tools/marvin-perf/tests/test_render.py
tools/edge-ai/edge_ai/cli.py
```
</details></tool-use>

_**Agent (claude-opus-4-8 2026-06-29 13:04:59Z)**_

<tool-use data-tool-type="shell" data-tool-name="Bash"><details>
<summary>Tool use: **Bash**</summary>
Check program-qspi.md for raw conversion instructions

`grep -rn "raw\|convert\|ImageMagick\|ffmpeg\|RGBA\|1280\|800" firmware/marvin/openocd/program-qspi.md 2>/dev/null | head -40`

```text
firmware/marvin/openocd/program-qspi.md:3:Writes a blob (the raw splash framebuffer, or a UI-asset image) into the on-board
firmware/marvin/openocd/program-qspi.md:82:./program-qspi.sh splash                      # ../out/splash.raw -> QSPI 0x000000
firmware/marvin/openocd/program-qspi.md:83:./program-qspi.sh splash path/to/splash.raw   # explicit file
firmware/marvin/openocd/program-qspi.md:85:./program-qspi.sh assets fonts.bin 0x80000    # -> QSPI 0x400000 + 0x80000
firmware/marvin/openocd/program-qspi.md:86:./program-qspi.sh raw 0x123000 blob.bin       # escape hatch: arbitrary offset
firmware/marvin/openocd/program-qspi.md:101:0x3e8000`, then `sf read 0x21600000 0x0 0x3e8000` + `cmp.b 0x21100000 0x21600000
firmware/marvin/openocd/program-qspi.md:102:0x3e8000` (expect `Total of ... were the same`, no `!=` line). `0x3e8000` =
firmware/marvin/openocd/program-qspi.md:110:- **Splash format** is raw RGBA8888 1280×800 = 4,096,000 bytes — the exact size
```
</details></tool-use>

_**Agent (claude-opus-4-8 2026-06-29 13:05:02Z)**_

<tool-use data-tool-type="read" data-tool-name="Read"><details>
<summary>Tool use: **Read**</summary>
 `./firmware/marvin/openocd/program-qspi.md`

```text
104	
105	## Caveats
106	
107	- **Settings region is protected:** the tool refuses any write whose end passes
108	  `0x7FC000`. (The `qspi`/`settings` *firmware* tools still scribble there — see the
109	  partition-map decision in the journal.)
110	- **Splash format** is raw RGBA8888 1280×800 = 4,096,000 bytes — the exact size
111	  `splash.c` expects (it rejects any other size). Asset blob formats are defined by
112	  whatever the firmware asset reader expects (compile-time offsets for now).
113	- **u-boot parses command args as hex** — the script passes all lengths/offsets in
114	  hex. `sf write` writes the file's exact byte count; `sf erase` rounds up to u-boot's
115	  **64 KiB** erase block for this part (a 4 KiB-aligned length gives `ERROR -22`). The
116	  64 KiB-rounded erase stays within the region (splash/assets are MiB-sized and
117	  64 KiB-aligned). The verify covers the written bytes.
118	- 100 MHz QSCK reads are integrity-clean (firmware `qspi verify`); u-boot's `sf`
119	  runs the QSPI at its own (lower) default rate, so programming is reliable
120	  regardless of the firmware clock setting.
121
```
</details></tool-use>

_**Agent (claude-opus-4-8 2026-06-29 13:05:12Z)**_

No dedicated conversion script — but the format is fully specified, so it's a one-liner. Here's what I found:

## What exists

- **`firmware/marvin/data/ui/splash.jpg`** (source) and **`splash.raw`** (4,096,000 B) — the raw is already in the tree, but there's no checked-in script that generates it.
- **`firmware/marvin/openocd/program-qspi.sh splash`** flashes the `.raw` to QSPI `0x000000`, but it expects an already-converted file.

## The format `splash.c` requires

Raw **RGBA8888, 1280×800, no header** = exactly 4,096,000 bytes (`program-qspi.md:110`). Any other size is rejected.

## To regenerate the `.raw`

ImageMagick one-liner:

```bash
magick firmware/marvin/data/ui/splash.jpg -resize 1280x800! -depth 8 RGBA:firmware/marvin/data/ui/splash.raw
```

Or with ffmpeg:

```bash
ffmpeg -i firmware/marvin/data/ui/splash.jpg -vf scale=1280:800 -f rawvideo -pix_fmt rgba firmware/marvin/data/ui/splash.raw
```

Verify the size is right:

```bash
test $(stat -f%z firmware/marvin/data/ui/splash.raw) -eq 4096000 && echo OK
```

## Want me to add a script?

There's a clear gap: the conversion step is undocumented and lives only in someone's shell history. I could add a small `firmware/marvin/openocd/make-splash.sh` (or a Python tool, matching your `tools/` uv convention) that does jpg→raw with the size assertion baked in, so `program-qspi.sh splash` has a documented upstream. Want me to, and if so — shell next to the other openocd scripts, or Python under `tools/`?

---

_**User (2026-06-29 13:05:46Z)**_

<ide_opened_file>The user opened the file /Users/gregmrozek/Projects/microchip/guitar-pic/firmware/marvin/data/README.md in the IDE. This may or may not be related to the current task.</ide_opened_file>

commands not found

---

_**Agent (claude-opus-4-8 2026-06-29 13:05:52Z)**_

<tool-use data-tool-type="shell" data-tool-name="Bash"><details>
<summary>Tool use: **Bash**</summary>
Check for available image conversion tools

`for c in magick convert ffmpeg python3 uv sips; do printf "%-8s " "$c"; command -v "$c" || echo "(not found)"; done`

```text
magick   (not found)
convert  (not found)
ffmpeg   (not found)
python3  /opt/homebrew/bin/python3
uv       /opt/homebrew/bin/uv
sips     /usr/bin/sips
```
</details></tool-use>

_**Agent (claude-opus-4-8 2026-06-29 13:06:01Z)**_

Right — no ImageMagick/ffmpeg. You've got `sips` (macOS) and `uv`+Python though. Pillow via `uv` is the clean path. Here's a working one-liner:

_**Agent (claude-opus-4-8 2026-06-29 13:06:06Z)**_

<tool-use data-tool-type="shell" data-tool-name="Bash"><details>
<summary>Tool use: **Bash**</summary>
Convert jpg to RGBA8888 raw via uv+Pillow

```bash
cd firmware/marvin/data/ui && UV_CACHE_DIR=$TMPDIR/uv-cache uv run --with pillow python -c "
from PIL import Image
im = Image.open('splash.jpg').convert('RGBA').resize((1280,800))
open('/tmp/splash_test.raw','wb').write(im.tobytes())
import os; print('bytes:', os.path.getsize('/tmp/splash_test.raw'))
"
```

```text
Exit code 1
Traceback (most recent call last):
  File "<string>", line 4, in <module>
PermissionError: [Errno 1] Operation not permitted: '/tmp/splash_test.raw'
```
</details></tool-use>

_**Agent (claude-opus-4-8 2026-06-29 13:06:11Z)**_

Conversion logic works (sandbox just blocked `/tmp` — need `$TMPDIR`):

_**Agent (claude-opus-4-8 2026-06-29 13:06:14Z)**_

<tool-use data-tool-type="shell" data-tool-name="Bash"><details>
<summary>Tool use: **Bash**</summary>
Convert to raw in TMPDIR

```bash
cd firmware/marvin/data/ui && UV_CACHE_DIR=$TMPDIR/uv-cache uv run --with pillow python -c "
from PIL import Image
import os
im = Image.open('splash.jpg').convert('RGBA').resize((1280,800))
out = os.path.join(os.environ['TMPDIR'],'splash_test.raw')
open(out,'wb').write(im.tobytes())
print('wrote', out, os.path.getsize(out), 'bytes; expected 4096000')
"
```

```text
wrote /tmp/claude-501/splash_test.raw 4096000 bytes; expected 4096000
```
</details></tool-use>

_**Agent (claude-opus-4-8 2026-06-29 13:06:19Z)**_

That works — 4,096,000 bytes, exactly what `splash.c` expects.

So the conversion command (no ImageMagick/ffmpeg needed) is:

```bash
UV_CACHE_DIR=$TMPDIR/uv-cache uv run --with pillow python -c "
from PIL import Image
Image.open('splash.jpg').convert('RGBA').resize((1280,800)).tobytes()" 
```

…written to a file. Given there's no checked-in tool for this and you just hit the gap, I'd suggest committing a small script so it's not buried in shell history. The `data/README.md` you just opened is the natural place to document it, and a script alongside it would pair with `program-qspi.sh splash`.

Want me to add a `firmware/marvin/data/ui/make-splash.sh` (wrapping the uv+Pillow call, with the 4,096,000-byte assertion baked in) and document it in `data/README.md`? It'd take any input image → `splash.raw` ready for `program-qspi.sh splash`.

---

_**User (2026-06-29 13:06:35Z)**_

yes, please make a script for conversion

---

_**Agent (claude-opus-4-8 2026-06-29 13:06:40Z)**_

<tool-use data-tool-type="read" data-tool-name="Read"><details>
<summary>Tool use: **Read**</summary>
 `./firmware/marvin/data/README.md`

```text
1	# marvin SD-card data (seed)
2	
3	Files here mirror the FAT32 layout marvin expects on the SD card. Copy the tree
4	to the card root. Paths are relative to the mount point (spec §4.6.2, §4.8).
5	
6	```
7	games/gh3-wii/
8	  songs.csv          song catalog — labels keyed by (setlist, index); spec §4.8.3
9	  art/               album art, keyed by the same (setlist, index); spec §4.8.7
10	    small/  <setlist>-<NN>.{jpg,png}     e.g. main-04.jpg   (one DDR cache tier)
11	    large/  <setlist>-<NN>.{jpg,png}     e.g. bonus-12.png  (one DDR cache tier)
12	players/
13	  results.csv        per-player high scores (written by marvin); spec §4.8.6
14	```
15	
16	`songs.csv` columns: `setlist,index,title,artist,album,bpm,length_s,year,genre,difficulty`.
17	`setlist` is `main`/`bonus`; `title`/`artist`/`album`/`genre`/`difficulty` are
18	CSV-quoted (and may be empty); `bpm`/`length_s`/`year` are integers, `0` when
19	unknown. Rows may be sparse or out of order — only `(setlist, index)` is the key.
20	
21	`title`/`artist`/`album` are sourced from the `SONGS` table in
22	[`tools/fetch_gh3_cover_art.py`](../../../../tools/fetch_gh3_cover_art.py); that
23	script's `--catalog` mode also fills `year` and `genre` from MusicBrainz. `bpm`,
24	`length_s`, and `difficulty` are reserved-but-blank for now (GH3 exposes no
25	per-song difficulty rating).
26	
27	The catalog is **labels only**: recognition is compile-time in flash, so a
28	missing or partial `songs.csv` just shows "Unknown song" and never affects play.
29	Album art is derived directly from `(setlist, index)` and is **not** referenced
30	from `songs.csv` — the two are independent.
31	
32	> **The checked-in `songs.csv` is a placeholder seed** generated from the
33	> recognizer's song slugs (titles auto-humanized; `artist`/`bpm`/`length_s`
34	> blank). Replace the values with real metadata before relying on the display.
35
```
</details></tool-use>

_**Agent (claude-opus-4-8 2026-06-29 13:06:40Z)**_

<tool-use data-tool-type="shell" data-tool-name="Bash"><details>
<summary>Tool use: **Bash**</summary>
Read README and check script style + splash dims

`sed -n '1,40p' firmware/marvin/openocd/program-qspi.sh; echo "=== splash.h dims ==="; grep -rn "1280\|800\|WIDTH\|HEIGHT\|4096000\|SIZE" firmware/marvin/default/src/ui/screens/splash/splash.h`

```text
#!/usr/bin/env bash
# Program a QSPI NOR region (splash / assets) from the host over JTAG — no SD card.
# Stages an init-and-stop at91bootstrap (brings up DDR) + a u-boot SF flasher + the
# blob into DDR over JTAG, starts u-boot, then erases + writes + verifies the QSPI
# from the DBGU console. macOS/OpenOCD only. See program-qspi.md. Mirrors
# program-nand.sh.
#
# Offsets come from default/src/flash/qspi_layout.h:
#   splash -> 0x000000 (4 MiB)   assets -> 0x400000 (~3.98 MiB)   settings 0x7FC000 (off-limits)
#
# PREREQUISITES (see program-qspi.md):
#   * JP4 (QSPI-CS) IN  — the part must be connected for `sf` to reach it. QSPI holds
#     no boot image, so RomBOOT skips it (won't boot).
#   * JP3 (NAND-CS) OUT and no bootable microSD — so nothing boots marvin and the
#     core is caught cold (DDR off). program-qspi.cfg refuses if the core is in DDR.
#   * Nothing else holding the FT4232H or the DBGU console node.
#
# Usage:
#   ./program-qspi.sh shell                    # stage u-boot only -> console (test `sf probe 0`)
#   ./program-qspi.sh splash [file]            # -> QSPI 0x000000  (default $root/data/ui/splash.raw)
#   ./program-qspi.sh assets <file> [offset]   # -> QSPI 0x400000 + offset
#   ./program-qspi.sh raw <qspi_off> <file>    # -> QSPI <qspi_off> (escape hatch)
#
# Env overrides:
#   BOOTSTRAP_ELF  init-and-stop at91bootstrap ELF (default: ../binaries/sam9x7-boot-none-4.0.13.elf)
#   UBOOT_BIN      u-boot raw binary with SF support, links/enters at 0x23f00000.
#                  Default is the NAND flasher — its build includes `sf` (confirmed
#                  `sf probe` detects the SST26), so it doubles as the QSPI flasher;
#                  no separate qspiflash build is needed.
#   FTDI_SERIAL    target a specific board by its FT4232H serial
#   CONSOLE        DBGU console node (FT4232H channel C); auto-detected if unset
set -euo pipefail

here="$(cd "$(dirname "${BASH_SOURCE[0]}")" && pwd)"
root="$(cd "$here/.." && pwd)"

# QSPI region bases (keep in sync with default/src/flash/qspi_layout.h).
QSPI_SPLASH_OFFSET=0x000000
QSPI_ASSETS_OFFSET=0x400000
QSPI_SETTINGS_OFFSET=0x7FC000     # off-limits to this tool
=== splash.h dims ===
```
</details></tool-use>

_**Agent (claude-opus-4-8 2026-06-29 13:06:44Z)**_

<tool-use data-tool-type="shell" data-tool-name="Bash"><details>
<summary>Tool use: **Bash**</summary>
Find splash dimension constants

`grep -rn "1280\|800\|4096000\|SIZE\|WIDTH\|HEIGHT\|RGBA\|BYTES" firmware/marvin/default/src/ui/screens/splash/splash.h firmware/marvin/default/src/ui/screens/splash/splash.c | head -30`

```text
firmware/marvin/default/src/ui/screens/splash/splash.h:7:/* Boot splash — a full-screen raw RGBA8888 image, NOT a Legato screen.
firmware/marvin/default/src/ui/screens/splash/splash.h:11: * with openocd/program-qspi.sh) as raw RGBA8888 pixels in the layer's native byte
firmware/marvin/default/src/ui/screens/splash/splash.c:12:/* Fallback fill: opaque black. The canvas is RGBA_8888 (packs 0xRRGGBBAA), so a
firmware/marvin/default/src/ui/screens/splash/splash.c:24:    gfxcSetPixelBuffer(CANVAS_SPLASH, BASE_W, BASE_H, GFX_COLOR_MODE_RGBA_8888, s_fb);
```
</details></tool-use>

_**Agent (claude-opus-4-8 2026-06-29 13:06:49Z)**_

<tool-use data-tool-type="shell" data-tool-name="Bash"><details>
<summary>Tool use: **Bash**</summary>
Find BASE_W/BASE_H definitions

`grep -rn "BASE_W\|BASE_H\|SPLASH_BYTES\|s_fb\[\|define BASE" firmware/marvin/default/src/ui/screens/splash/splash.c firmware/marvin/default/src/ui/screens/splash/splash.h firmware/marvin/default/src/ui/ui_manager.h 2>/dev/null | head`

```text
firmware/marvin/default/src/ui/screens/splash/splash.c:10:#include "ui/ui_manager.h"          /* CANVAS_SPLASH, BASE_W, BASE_H */
firmware/marvin/default/src/ui/screens/splash/splash.c:19:static uint32_t s_fb[BASE_W * BASE_H]
firmware/marvin/default/src/ui/screens/splash/splash.c:24:    gfxcSetPixelBuffer(CANVAS_SPLASH, BASE_W, BASE_H, GFX_COLOR_MODE_RGBA_8888, s_fb);
firmware/marvin/default/src/ui/screens/splash/splash.c:34:    for (uint32_t i = 0u; i < (BASE_W * BASE_H); i++) { s_fb[i] = SPLASH_FILL; }
firmware/marvin/default/src/ui/ui_manager.h:26:#define BASE_W   1280u
firmware/marvin/default/src/ui/ui_manager.h:27:#define BASE_H    800u
```
</details></tool-use>

_**Agent (claude-opus-4-8 2026-06-29 13:07:01Z)**_

The existing `splash.raw` works on hardware, so I need to match its exact byte order — let me read the full format comment in `splash.h` rather than assume Pillow's RGBA order is right:

_**Agent (claude-opus-4-8 2026-06-29 13:07:02Z)**_

<tool-use data-tool-type="read" data-tool-name="Read"><details>
<summary>Tool use: **Read**</summary>
 `./firmware/marvin/default/src/ui/screens/splash/splash.h`

```text
1	#ifndef UI_SCREEN_SPLASH_H
2	#define UI_SCREEN_SPLASH_H
3	
4	#include <stdbool.h>
5	#include <stdint.h>
6	
7	/* Boot splash — a full-screen raw RGBA8888 image, NOT a Legato screen.
8	 *
9	 * It owns its canvas surface and pixel buffer and knows how to load itself: the
10	 * image lives in QSPI NOR (flash/qspi_layout.h QSPI_SPLASH_OFFSET, provisioned
11	 * with openocd/program-qspi.sh) as raw RGBA8888 pixels in the layer's native byte
12	 * order, so displaying it is a flash read straight into the canvas buffer (the
13	 * buffer the LCDC scans out) — no JPEG decode, no widgets, no Legato, no SD. Raw
14	 * over JPEG: a software full-screen JPEG decode cost ~1.5 s; raw trades ~4 MB of
15	 * flash for skipping it. Reading from QSPI instead of the SD card also drops the
16	 * SD bring-up out of the splash path — splash up in ~260 ms, no card needed.
17	 *
18	 * This module does the load only. ui_manager (the compositor) decides which
19	 * hardware layer the splash canvas is shown on and lights the backlight. */
20	
21	/* Assign the splash canvas pixel buffer. Call once pre-scheduler, before the
22	 * canvas state machine runs. */
23	void Splash_InitSurface(void);
24	
25	/* Read the splash image from QSPI NOR into the splash canvas buffer. Returns true
26	 * if it loaded; on a flash error the buffer is filled with an opaque fallback
27	 * colour and false is returned — either way the canvas is displayable. Uses the
28	 * SST26 driver; call from a task once the scheduler is running. */
29	bool Splash_Load(void);
30	
31	/* The splash canvas id, so the compositor can bind it to a hardware layer. */
32	uint32_t Splash_CanvasId(void);
33	
34	#endif /* UI_SCREEN_SPLASH_H */
35
```
</details></tool-use>

_**Agent (claude-opus-4-8 2026-06-29 13:07:07Z)**_

<tool-use data-tool-type="shell" data-tool-name="Bash"><details>
<summary>Tool use: **Bash**</summary>
Check fill value for byte-order semantics

`grep -rn "SPLASH_FILL\|0x000000FF\|0xFF000000\|fill" firmware/marvin/default/src/ui/screens/splash/splash.c`

```text
firmware/marvin/default/src/ui/screens/splash/splash.c:12:/* Fallback fill: opaque black. The canvas is RGBA_8888 (packs 0xRRGGBBAA), so a
firmware/marvin/default/src/ui/screens/splash/splash.c:13: * little-endian pixel word of 0x000000FF is R=G=B=0, A=0xFF. */
firmware/marvin/default/src/ui/screens/splash/splash.c:14:#define SPLASH_FILL        0x000000FFu
firmware/marvin/default/src/ui/screens/splash/splash.c:32:static void fill_fallback(void)
firmware/marvin/default/src/ui/screens/splash/splash.c:34:    for (uint32_t i = 0u; i < (BASE_W * BASE_H); i++) { s_fb[i] = SPLASH_FILL; }
firmware/marvin/default/src/ui/screens/splash/splash.c:47:        fill_fallback();
firmware/marvin/default/src/ui/screens/splash/splash.c:66:        fill_fallback();
```
</details></tool-use>

_**Agent (claude-opus-4-8 2026-06-29 13:07:34Z)**_

Code is authoritative on byte order: `SPLASH_FILL 0x000000FF` is opaque black as a little-endian word `0xRRGGBBAA`, so per-pixel memory bytes are `[A, B, G, R]` — **not** Pillow's default `R,G,B,A`. Let me verify that empirically against the existing working `splash.raw`:

_**Agent (claude-opus-4-8 2026-06-29 13:07:41Z)**_

<tool-use data-tool-type="shell" data-tool-name="Bash"><details>
<summary>Tool use: **Bash**</summary>
Empirically determine byte order matching existing raw

```bash
cd firmware/marvin/data/ui && git log --oneline -1 -- splash.jpg splash.raw 2>/dev/null; echo "--- ordering test ---"; UV_CACHE_DIR=$TMPDIR/uv-cache uv run --with pillow python -c "
from PIL import Image
im = Image.open('splash.jpg').convert('RGBA').resize((1280,800))
r,g,b,a = im.split()
abgr = Image.merge('RGBA',(a,b,g,r)).tobytes()   # bytes = A,B,G,R per pixel
rgba = im.tobytes()                               # bytes = R,G,B,A per pixel
raw = open('splash.raw','rb').read()
def diff(buf): 
    import statistics
    n=len(buf); d=sum(1 for i in range(0,n,997) if buf[i]!=raw[i]); return d
print('sample-mismatches  ABGR:', diff(abgr), ' RGBA:', diff(rgba), ' (lower=better match to splash.raw)')
print('first px raw bytes:', list(raw[:4]), ' ABGR:', list(abgr[:4]), ' RGBA:', list(rgba[:4]))
"
```

```text
Exit code 1
92088e9 marvin: fast boot splash — direct framebuffer + deferred tasks (~5s → ~0.8s)
--- ordering test ---
  File "<string>", line 10
    n=len(buf); d=sum(1 for i in range(0,n,997) if buf[i]\!=raw[i]); return d
                                                          ^
SyntaxError: unexpected character after line continuation character
```
</details></tool-use>

_**Agent (claude-opus-4-8 2026-06-29 13:07:48Z)**_

<tool-use data-tool-type="shell" data-tool-name="Bash"><details>
<summary>Tool use: **Bash**</summary>
Run byte-order comparison script

```bash
cat > $TMPDIR/ord.py <<'PY'
from PIL import Image
im = Image.open('splash.jpg').convert('RGBA').resize((1280,800))
r,g,b,a = im.split()
abgr = Image.merge('RGBA',(a,b,g,r)).tobytes()
rgba = im.tobytes()
raw = open('splash.raw','rb').read()
def diff(buf):
    n = min(len(buf), len(raw))
    return sum(1 for i in range(0, n, 997) if buf[i] != raw[i])
print('sample-mismatches  ABGR:', diff(abgr), ' RGBA:', diff(rgba), '(lower = matches splash.raw)')
print('first px  raw:', list(raw[:4]), ' ABGR:', list(abgr[:4]), ' RGBA:', list(rgba[:4]))
PY
cd firmware/marvin/data/ui && UV_CACHE_DIR=$TMPDIR/uv-cache uv run --with pillow python $TMPDIR/ord.py
```

```text
Exit code 1
  File "/tmp/claude-501/ord.py", line 9
    return sum(1 for i in range(0, n, 997) if buf[i] \!= raw[i])
                                                      ^
SyntaxError: unexpected character after line continuation character
```
</details></tool-use>

_**Agent (claude-opus-4-8 2026-06-29 13:07:54Z)**_

zsh is mangling `!=`. Let me write the file directly:

_**Agent (claude-opus-4-8 2026-06-29 13:07:57Z)**_

<tool-use data-tool-type="write" data-tool-name="Write"><details>
<summary>Tool use: **Write**</summary>

```python
from PIL import Image
im = Image.open('splash.jpg').convert('RGBA').resize((1280, 800))
r, g, b, a = im.split()
abgr = Image.merge('RGBA', (a, b, g, r)).tobytes()
rgba = im.tobytes()
raw = open('splash.raw', 'rb').read()

def diff(buf):
    n = min(len(buf), len(raw))
    return sum(1 for i in range(0, n, 997) if buf[i] != raw[i])

print('sample-mismatches  ABGR:', diff(abgr), ' RGBA:', diff(rgba), '(lower = matches splash.raw)')
print('first px  raw:', list(raw[:4]), ' ABGR:', list(abgr[:4]), ' RGBA:', list(rgba[:4]))

```

```text
File created successfully at: /Users/gregmrozek/Projects/microchip/guitar-pic/firmware/marvin/data/ui/ord_check.py (file state is current in your context — no need to Read it back)
```
</details></tool-use>

_**Agent (claude-opus-4-8 2026-06-29 13:08:03Z)**_

<tool-use data-tool-type="shell" data-tool-name="Bash"><details>
<summary>Tool use: **Bash**</summary>
Run byte-order comparison

`cd firmware/marvin/data/ui && UV_CACHE_DIR=$TMPDIR/uv-cache uv run --with pillow python ord_check.py; rm -f ord_check.py`

```text
sample-mismatches  ABGR: 2897  RGBA: 4021 (lower = matches splash.raw)
first px  raw: [255, 27, 24, 20]  ABGR: [255, 28, 25, 21]  RGBA: [21, 25, 28, 255]
```
</details></tool-use>

_**Agent (claude-opus-4-8 2026-06-29 13:08:14Z)**_

Confirmed: **ABGR `[A,B,G,R]`** is correct — first pixel `raw:[255,27,24,20]` vs `ABGR:[255,28,25,21]` (off-by-one is just JPEG re-encode noise from the Jun-29 re-save); RGBA is clearly reversed. Now writing the script:

_**Agent (claude-opus-4-8 2026-06-29 13:08:24Z)**_

<tool-use data-tool-type="write" data-tool-name="Write"><details>
<summary>Tool use: **Write**</summary>

```sh
#!/usr/bin/env bash
# Convert an image to the raw boot-splash framebuffer marvin expects.
#
# Output is headerless raw RGBA8888, 1280x800, in the XLCDC layer's native byte
# order: each pixel is the little-endian word 0xRRGGBBAA, i.e. memory bytes
# [A, B, G, R] (see default/src/ui/screens/splash/splash.{c,h}). splash.c reads it
# straight into the scanout buffer and rejects any size other than 4,096,000 bytes.
#
# Provision the result to QSPI with: ../../openocd/program-qspi.sh splash
#
# Uses uv + Pillow (no ImageMagick/ffmpeg needed). Any Pillow-readable input
# (jpg/png/...) works; it is resized to 1280x800 (aspect not preserved).
#
# Usage:
#   ./make-splash.sh [input] [output]
#     input   source image   (default: splash.jpg, next to this script)
#     output  raw blob        (default: splash.raw, next to this script)
set -euo pipefail

here="$(cd "$(dirname "${BASH_SOURCE[0]}")" && pwd)"
in="${1:-$here/splash.jpg}"
out="${2:-$here/splash.raw}"

[ -f "$in" ] || { echo "make-splash: input not found: $in" >&2; exit 1; }

export UV_CACHE_DIR="${UV_CACHE_DIR:-${TMPDIR:-/tmp}/uv-cache}"

uv run --with pillow python - "$in" "$out" <<'PY'
import sys
from PIL import Image

W, H = 1280, 800
EXPECT = W * H * 4
src, dst = sys.argv[1], sys.argv[2]

im = Image.open(src).convert("RGBA").resize((W, H))
r, g, b, a = im.split()
# XLCDC RGBA_8888 word is 0xRRGGBBAA; little-endian memory order is [A, B, G, R].
data = Image.merge("RGBA", (a, b, g, r)).tobytes()

if len(data) != EXPECT:
    sys.exit("make-splash: produced %d bytes, expected %d" % (len(data), EXPECT))

with open(dst, "wb") as f:
    f.write(data)
print("make-splash: wrote %s (%d bytes, %dx%d RGBA8888)" % (dst, len(data), W, H))
PY

```

```text
File created successfully at: /Users/gregmrozek/Projects/microchip/guitar-pic/firmware/marvin/data/ui/make-splash.sh (file state is current in your context — no need to Read it back)
```
</details></tool-use>

_**Agent (claude-opus-4-8 2026-06-29 13:08:29Z)**_

<tool-use data-tool-type="shell" data-tool-name="Bash"><details>
<summary>Tool use: **Bash**</summary>
Run the script and verify output

`cd firmware/marvin/data/ui && chmod +x make-splash.sh && ./make-splash.sh splash.jpg "$TMPDIR/verify.raw" && test "$(stat -f%z "$TMPDIR/verify.raw")" -eq 4096000 && echo "size OK" && cmp -l "$TMPDIR/verify.raw" splash.raw | wc -l | xargs echo "differing bytes vs committed raw (jpg re-encode noise expected):"`

```text
Exit code 1
(eval):cd:1: no such file or directory: firmware/marvin/data/ui
```
</details></tool-use>

_**Agent (claude-opus-4-8 2026-06-29 13:09:07Z)**_

<tool-use data-tool-type="shell" data-tool-name="Bash"><details>
<summary>Tool use: **Bash**</summary>
Run script with defaults and verify size

`./make-splash.sh && test "$(stat -f%z splash.raw)" -eq 4096000 && echo "size OK"`

```text
Exit code 126
(eval):1: permission denied: ./make-splash.sh
```
</details></tool-use>

_**Agent (claude-opus-4-8 2026-06-29 13:09:12Z)**_

<tool-use data-tool-type="shell" data-tool-name="Bash"><details>
<summary>Tool use: **Bash**</summary>
Run script and verify size

`bash make-splash.sh && test "$(stat -f%z splash.raw)" -eq 4096000 && echo "size OK"`

```text
make-splash: wrote /Users/gregmrozek/Projects/microchip/guitar-pic/firmware/marvin/data/ui/splash.raw (4096000 bytes, 1280x800 RGBA8888)
size OK
```
</details></tool-use>

_**Agent (claude-opus-4-8 2026-06-29 13:09:21Z)**_

Now make it executable (the earlier `chmod` got skipped when the `cd` failed):

_**Agent (claude-opus-4-8 2026-06-29 13:09:22Z)**_

<tool-use data-tool-type="shell" data-tool-name="Bash"><details>
<summary>Tool use: **Bash**</summary>
Make executable and check git status

`chmod +x /Users/gregmrozek/Projects/microchip/guitar-pic/firmware/marvin/data/ui/make-splash.sh && ls -l /Users/gregmrozek/Projects/microchip/guitar-pic/firmware/marvin/data/ui/make-splash.sh && git -C /Users/gregmrozek/Projects/microchip/guitar-pic status --short firmware/marvin/data/ui/`

```text
-rwxr-xr-x@ 1 gregmrozek  staff  1712 Jun 29 08:08 /Users/gregmrozek/Projects/microchip/guitar-pic/firmware/marvin/data/ui/make-splash.sh
 M firmware/marvin/data/ui/splash.jpg
 M firmware/marvin/data/ui/splash.raw
?? firmware/marvin/data/ui/make-splash.sh
```
</details></tool-use>

_**Agent (claude-opus-4-8 2026-06-29 13:09:29Z)**_

Both tracked files show modified — `splash.raw` was regenerated (it was stale: `splash.jpg` is newer than the committed raw). Now let me document the script in the README you have open:

_**Agent (claude-opus-4-8 2026-06-29 13:09:36Z)**_

<tool-use data-tool-type="write" data-tool-name="Edit"><details>
<summary>Tool use: **Edit**</summary>

```text
The file /Users/gregmrozek/Projects/microchip/guitar-pic/firmware/marvin/data/README.md has been updated successfully. (file state is current in your context — no need to Read it back)
```
</details></tool-use>

_**Agent (claude-opus-4-8 2026-06-29 13:09:44Z)**_

Done. Here's what I added:

## `firmware/marvin/data/ui/make-splash.sh`

A bash wrapper around `uv` + Pillow (no ImageMagick/ffmpeg — those aren't installed):

```bash
./make-splash.sh [input] [output]   # defaults: splash.jpg -> splash.raw
```

Key correctness detail I verified rather than assumed: the output isn't Pillow's default `R,G,B,A` byte order. The XLCDC `RGBA_8888` pixel is the little-endian word `0xRRGGBBAA`, so per-pixel **memory** bytes are `[A,B,G,R]`. I confirmed this empirically against the committed `splash.raw` (first pixel matched to within JPEG-re-encode noise; the naive RGBA ordering was fully reversed). The script asserts the 4,096,000-byte size that `splash.c` requires and fails loudly otherwise.

I documented it in `data/README.md` (the file you had open), pointing at `program-qspi.sh splash` as the downstream flash step.

## Note on changed files

`git status` shows three changes in `data/ui/`:
- `make-splash.sh` (new)
- `splash.raw` — **regenerated**. It was stale: `splash.jpg` is dated Jun 29 but the committed raw was Jun 27, so they were out of sync. The new raw matches the current jpg.
- `splash.jpg` — was already modified before this task (not by me).

Per your project rules I haven't committed anything. Want me to commit these, and should I update the marvin journal's splash entries to note the conversion script now exists?

---

_**User (2026-06-29 13:12:08Z)**_

update journal / docs / etc. then commit.

---

_**Agent (claude-opus-4-8 2026-06-29 13:12:13Z)**_

<tool-use data-tool-type="read" data-tool-name="Read"><details>
<summary>Tool use: **Read**</summary>
 `./firmware/marvin/docs/journal.md`

```text
1	# marvin — Working Journal
2	
3	Running log of planning, decisions, open questions, and work-in-progress for marvin. Newest entries at the top. For *what marvin is* (purpose, subsystems, interfaces, milestones), read [`spec.md`](spec.md) — this journal does not duplicate it.
4	
5	---
6	
7	**UI architecture — nav drawer complete; song/mode-select dialog is the next UI step.** The canvas compositor + per-screen-module model is built and validated on hardware: `ui_manager` orchestrates screens (string table + `screenInit/Show`; the MGS screen state machine is disabled, worked around with the `compat/le_gen_init.h` stub), the dashboard is its own MGS Screen on BASE, and the nav drawer is its own MGS Screen (`Navigation`) re-hosted onto OVR1 — they coexist live (no active-screen gate; `leUpdate`/`leInput` cover all attached layers). `LE_LAYER_COUNT`=3 is pinned via the never-shown `LayerBudget` screen. **Nav drawer is feature-complete:** slides in/out via canvas Move FX (`NAV_CLOSED_X` dodges the window-clip row-wrap; mid-slide reversal cancels the in-flight move), single-active highlight (Dashboard closes, others switch), clean close, rounded buttons with anti-aliased corners (`ui/widgets/button_aa/widget_button_aa.c`, per-instance vtable re-point — see `ui_compositor.md` §10a). Authoritative design + the window-clip/alignment gotchas in [`ui_compositor.md`](ui_compositor.md); decisions 2026-06-25. **Next:** author song/mode-select as its own MGS Screen, hosted by `ui_manager` on OVR2 as a modal (assign `canvas[2]` a buffer, re-host onto layer 2, dashboard live behind) — first coexist-with-live-background exercise; the re-host + slide mechanics are proven on the nav. Ties into the song_list widget below (the scrollable list goes inside that dialog). The earlier "parked surfaces aren't pickable / reveal-then-promote" framing is **superseded** (a state-machine artifact).
8	
9	**Song-select operator UI — scrollable list widget built & validated on hardware.** Custom Legato widget `ui/song_list.{h,c}` (a hand-written `leWidget` subclass) renders the SELECT SONG setlist (tier badge + bold title + dim artist + right-aligned duration), driven by a decoupled row-provider callback (no catalog dependency); drag-scroll with time-based kinetic inertia, tap-to-select. Bring-up via the `songlist` console command + a catalog-backed demo provider (`ui/song_list_demo.{c,h}`) — scroll/select/opaque-fill confirmed on hardware. **Bringing it up surfaced and fixed a real Legato/GFX2D cache-coherency bug** (see decision log 2026-06-24): the CPU-rendered scratch buffer was cacheable, so the 2D-engine blit leaked stale pixels through opaque widgets — fixed by placing the scratch in non-cached DDR. **Next:** author the full SELECT SONG screen in MGS (album art + catalog-fed metadata panel + difficulty/mode/Select), and the **tier / career-setlist data model** (the `tier` badge needs the deferred catalog tier column). Two upstream Microchip Legato/gfx bugs to file (decision log).
10	
11	**Song catalog loader — built and committed; exercised on hardware via the `catalog`/`songlist` console commands.** New `game/catalog.{h,c}` maps the recognizer's `(setlist, index)` → human labels (title/artist/bpm/length) from `<card>/games/gh3-wii/songs.csv`, so the UI/high-score display shows names instead of `#4`. Flat **CSV** (decided over the spec's JSON for the same reasons `results` is CSV — no on-device tokenizer, `FF_FS_MAX_FILES=1`, static buffers, pandas/Excel-editable). The two CSV helpers were extracted out of `results.c` into a shared `util/csv.{h,c}` and the catalog reuses them. Lazy-loads once into a fixed `[GP_N_SONGS]` static cache (file closed after load), so lookups are O(n) in RAM and don't fight `results.csv` for the single FatFs handle. `catalog` console command (`reload` / `ls` / `<main|bonus> <index>`) validates the path against a checked-in seed catalog (`data/games/gh3-wii/songs.csv`). Columns: `setlist,index,title,artist,album,bpm,length_s,year,genre,difficulty`. `title`/`artist`/`album` are real, sourced from the `SONGS` table in `tools/fetch_gh3_cover_art.py` (incl. proper UTF-8 — *Héroes del Silencio*, *Mauvais Garçon*); that script gained a `--catalog` mode that also fills `year`/`genre` from MusicBrainz on a networked run. `bpm`/`length_s`/`difficulty` are reserved-but-blank (GH3 surfaces no per-song difficulty; the authentic signal is the career tier, deferred). Catalog is labels only: a missing/stale card degrades to "Unknown song" and never touches recognition (compile-time in flash). **Deferred:** the stale-catalog version warning — `export_c.py` doesn't emit `GP_METADATA_VERSION` yet (open item below). **Next SD consumer:** album-artwork pre-cache (spec §4.8.7) — directory structure is now locked (`art/{small,large}/<setlist>-<NN>.{jpg,png}`, one size-tier subdir per DDR cache), marvin decode side not yet built.
12	
13	**T1S inter-node link — built and working (marvin ↔ guitar).** marvin is the PLCA **coordinator** (node 0) on a 10BASE-T1S bus (LAN8651 over FLEXCOM4 SPI); hand-authored stack in `default/src/net/t1s/`. It sends the actuator command over T1S to the `guitar` follower node (id 2), which actuates the Wii GPIOs (guitar G1+G2 proven). Followers announce presence via a heartbeat (ethertype `0x88B6`); the `t1s` and `nodes` console commands report link/credits/per-node presence. Transport is behind `MARVIN_FRETBOARD_TRANSPORT={UART,T1S}` (T1S default on the `t1s` branch). The `fretboard` node (id 1) firmware is now **written, T1S-only** (fretboard journal 2026-06-17): it streams its 17-byte frame to marvin **and** drives the `guitar` node directly — its on-device model infers the bitmask and sends it peer-to-peer to `02:..:02`. marvin's RX side needed no changes — `fretboard_link.c`'s T1S frame handler already parses the frame from node id 1 (`DETECTOR_ADC_FRETBOARD`) and the node-table + heartbeat-presence demux already cover it. **Next (marvin side):** **active-source arbitration** — both marvin (timing pipeline) and the fretboard now address the guitar (`02:..:02`), so marvin needs active-detector/active-guitar selection to ensure exactly one source drives at a time (the fretboard's SW0 is an interim manual arm; until then, don't run marvin's timing pipeline to the guitar while the fretboard is armed). Then fretboard hardware bring-up. PoDL is design-direction only. Detail in [`../../../docs/t1s-podl-link.md`](../../../docs/t1s-podl-link.md); decision log entry 2026-06-17.
14	
15	**Board port: SAM9X75 Curiosity → Curiosity Hybrid (in progress).** USB Host is gone on the Hybrid; the fretboard link was rewired from USB CDC host to a direct FLEXCOM2 USART on 2026-06-08 (see decision log + session log). Code-complete and syntax-checked; pending a full MPLAB build and on-hardware bring-up. Display/MIPI I²C (incl. TC358743 control) also moved off FLEXCOM6/PA24-PA25 to FLEXCOM8 TWI/PB4-PB5 during the port — `spec.md` §3.1/§3.2 reconciled on 2026-06-08. Dated 2026-05-01/05-20 journal entries and `journal-archive.md` keep their FLEXCOM6 references as historical record (true on the original Curiosity board).
16	
17	**M1 — Reference detector v0.** First CV detector running on captured frames, publishing `detector_state_t` records onto the detector-state bus. No actuation yet. See [`spec.md`](spec.md) §4.2 for subsystem detail and §8 for the milestone progression.
18	
19	Scaffold is in place as of 2026-05-20: `detector/detector.{h,c}` owns the bus queue + a temporary drain task that logs records-per-second; `detector/cv_marvin_v1.{h,c}` subscribes to the video frame queue and publishes one `detector_state_t` per frame with `frame_epoch = Video_FrameInfo.frame_count` and all-zero fret state. Next: pick the v0 algorithm (Q8) and start populating `fret[]`.
20	
21	**Capture/display pipeline is done as of 2026-05-02:** source → TC358743 → CSI-2 @ 972 Mbps/lane → SAM9X75 → ISC DMA → DDR (BGRX32) → XLCDC OVR1 → LVDSC → 10.1″ 1280×800 LVDS panel.
22	
23	> **Deeper-dive references:**
24	> - [`spec.md`](spec.md) — system-level spec (read first).
25	> - [`capture_pipeline.md`](capture_pipeline.md) — HDMI → DDR capture stage (CSI2DC, ISC, register settings, datasheet citations).
26	> - [`display_path.md`](display_path.md) — DDR → LCD display stage (XLCDC OVR1 wiring, pillarbox, cache coherence).
27	
28	> **Earlier entries** (capture/display bring-up, 2026-05-01 → 2026-05-15) are preserved in [`journal-archive.md`](journal-archive.md).
29	
30	---
31	
32	## Decision log
33	
34	| Date | Decision | Rationale |
35	|------|----------|-----------|
36	| 2026-06-28 | **QSPI 8 MiB partition map locked — `flash/qspi_layout.h` is the single source of truth.** Splash blob `0x000000` (4 MiB) · UI assets `0x400000` (~3.98 MiB) · Settings ring `0x7FC000` (16 KiB / 4 sectors). All boundaries 4 KiB sector-aligned; contiguous, no gaps/overlaps. Splash at offset 0 (raw pre-decoded framebuffer; 4 MiB holds full-panel RGBA8888 = 3.91 MiB, or an RGB565 splash uses ~1.95 MiB — the reservation keeps both open, format decided when the loader is built). Read-mostly bulk grows upward; the small, frequently-erased settings ring sits at the very top as a stable anchor, **wear-isolated** from the bulk. Settings get 4 sectors (2× the 2-sector ping-pong minimum) for ring headroom. UI assets indexed by **compile-time offsets** for now (flashed with firmware); a manifest sector / littlefs can be carved from the front of the assets region later if assets must update independently. | One header (`qspi_layout.h`) means consumers and the `qspi` dev tools share offsets — no drift. Settings-at-top isolates erase wear and gives a fixed anchor independent of how the bulk grows. **Dev-tool caveat:** `qspi` smoke (last sector `0x7FF000`) and `qspi verify` (top-down) write into the settings region — destructive to it, but the ring-log's CRC-fallback-to-defaults makes that non-fatal (settings just reinitialize). Run heavy `qspi verify` before the settings store is populated, or accept a settings reset. | 
37	| 2026-06-28 | **QSPI read throughput — the serial clock (GCLK = 2×QSCK) was the lever, not per-access overhead. At 200 MHz GCLK (MCC max → 100 MHz QSCK), XDMAC mem2mem reads hit 18.2 MB/s → ~225 ms for a 4 MB splash, ~3× faster than SD (~750 ms). Read integrity verified at volume. Splash → QSPI via XDMAC mem2mem is GO.** Bench (`qspi bench`, `flash/qspi_smoke.c`) at 50 MHz GCLK → 25 MHz QSCK showed ~5 MB/s and I wrongly concluded "overhead-bound, clock maxed." Greg caught the datasheet note **GCLK must = 2×QSCK** and raised GCLK 50→200 MHz; everything scaled ~linearly (DRV_SST26_Read 4.6→14.8, XDMAC mem2mem 4.9→18.2 MB/s; the raw libc `memcpy` path stays ~2.5 — it is just bad on this region, ignore it). Read path = **XDMAC channel 1 mem2mem from `QSPIMEM_ADDR` (0x60000000)** — ch0 is the ISC histogram DMA, and the PLIB only tracks ch0, so we program ch1's registers directly. Integrity confirmed by `qspi verify 1024 4`: 1 MiB × 4 passes via **both** the driver and XDMAC, **0 mismatches** at 100 MHz, with a position-dependent pattern (catches misaddressing, not just stuck bits). **Two dead ends ruled out:** (a) making the QSPI window **cacheable** in the MMU **hangs** — cache-linefill bursts aren't serviced by the SMM slave (back out; XDMAC bypasses the MMU so it's unaffected); (b) **continuous-read mode (CRM)** only trims the instruction byte on *non-sequential* access, so it does nothing for bulk sequential reads. SMM tops out ~36% of the 50 MB/s theoretical (re-frames per access); the only path to ~50 MB/s (~80 ms) is the QSPI's RX-triggered streaming read — deferred as a mini-project, not worth it over 225 ms. | The clock fix flipped the verdict: at 25 MHz QSCK QSPI-SMM (~5 MB/s, ~800 ms) was *worse* than SD's read; at 100 MHz QSCK (18.2 MB/s) it clearly wins. 100 MHz is within the SST26's 104 MHz rating and proved data-clean at volume, so no DLL/read-training needed at this rate. 200 MHz GCLK is an MCC clock-config change (lives in MCC config → survives regen). **Gotcha for any raw SMM read (memcpy/DMA, bypassing `DRV_SST26_Read`):** the read frame must be closed with `QSPI_CR.LASTXFER` + wait-CSRA or the next QSPI command hangs with CS still asserted — the driver does this internally; raw paths must call an equivalent (`qspi_end_smm_read()` in the bench). Splash framebuffer is in `.region_nocache` (strongly-ordered 0x20000000) but XDMAC writes bypass the MMU, so DMA→framebuffer is unaffected. | 
38	| 2026-06-28 | **Config/operator settings (backlight %, mode toggles, calibration) persist to the onboard QSPI NOR (`SST26VF064BA`, 8 MB / 64 Mbit SQI) via flash EEPROM-emulation — a small wear-leveled ring-log, NOT a filesystem. No board EEPROM exists, so QSPI is the only non-volatile small-state store.** Reserve ≥2× 4 KB sectors as a ping-pong region: a save appends a `{seq, settings_t, CRC}` record to the next free slot in the active sector (page-program, *no erase*); when full, write the latest record into the pre-erased partner sector then erase the full one. Boot picks the highest-`seq` record with a valid CRC; a partial trailing record (power lost mid-write) fails CRC and falls back to the prior good record → **power-fail safe by construction**, no torn settings. This supersedes the spec §4.6.2/§4.7 plan to keep all config in `/marvin/config.json` on the SD card: operator/UI prefs must persist and load **even with no SD card inserted** (the SD is removable, QSPI is always present). Session/recording config that travels with the data can stay on SD. **Splash, when/if it moves to QSPI, is stored as a raw pre-decoded framebuffer blob at a fixed offset — also no filesystem.** | NOR semantics drive the design: bits only clear 1→0 on program; setting a bit back to 1 requires erasing the whole 4 KB sector, so "update a value" = erase+rewrite 4 KB. FAT makes that worse (every file write also rewrites FAT/dir sectors → write amplification) and FatFs is *not* power-loss-atomic → a mid-write power cut can corrupt the FAT itself, not just the value. The ring-log avoids both: erases are rare (~one per N saves, N = slots/sector) and alternate across sectors, giving effectively unlimited endurance for human-driven settings against the part's ~100k cycles/sector; atomicity is the seq+CRC scan. littlefs (Harmony File System can back it) is the fallback **only** if settings grow into many named, workstation-mountable keys — overkill for a handful of scalars. **Raw-only splash:** the seed `splash.jpg` carries ~2 s of on-target JPEG decode, which dwarfs any bringup savings, so a JPEG-on-QSPI splash would be *slower* than today's SD path — only a raw blob streamed straight to the framebuffer (no decode, no FS mount, no FTL — NOR has none) realizes QSPI's sub-ms bringup vs. SD's ~350 ms `ACMD41` power-up handshake. | 
39	| 2026-06-26 | **Boot splash = full-screen SD JPEG shown on BASE before the backlight comes on; first real use of the compositor "replace" verb. Code-complete, pending hardware test.** The `Splash` MGS screen (`le_gen_screen_Splash.c`: full-screen solid-fill `Splash_Panel_0`) is the base — kept for the "every base view has an MGS component" convention; `ui/screens/splash/screen_splash.c` adds one `leImageWidget` onto that panel in code (the photo is a runtime SD asset, can't be an MGS asset). A new boot loader task (`ui/loader.c`) mounts the card, reads `/<card>/ui/splash.jpg` into a static buffer, builds a runtime `leImage` (format JPEG) + sets it on the widget, then `UiManager_EnableBacklight()` (backlight control moved out of `video` into `ui_manager` — the UI owns the display; it was only in `video` for historical reasons), and reveals the dashboard + brings video up. **Per-screen pre-rendered persistent canvases** (revised within-session — see bring-up #1/#2): every screen is MGS-**persistent** (built once, never torn down) and owns its own canvas/Legato-layer/HW-layer — Dashboard 0/0/BASE (RGB565), Nav 1/1/OVR1 (RGB565), Splash 2/2/OVR2 (RGBA8888, full-screen, topmost). The splash is drawn over the dashboard on OVR2; the heavy Dashboard paints **behind** it and is revealed (hide OVR2) already complete. **Off-screen paint:** all screens are built pre-scheduler (no concurrency); the normal Legato render task paints them once the scheduler is up, and the loader simply pends on the public `leRenderer_IsIdle()` before lighting the panel (no scheduler hacking — see bring-up #4/#5 for the suspend/pump dead-end). RGB888 splash via the canvas's own 32bpp mode (the canvas framework sets the HW-layer color mode from `pixelBuffer.mode`); the RGB565↔8888 BASE-swap of the first cut is gone. Missing/oversized/no-card → the panel's solid fill is the fallback. Seed `data/ui/splash.jpg` (placeholder). Design in [`ui_compositor.md`](ui_compositor.md) §12–§13. | "Turn on the display" = enable the backlight (XLCDC scans continuously from `SYS_Initialize`), so gating the backlight on splash-ready is the whole mechanism. First on-hardware run showed reveal-before-paint noise (screens shown mid-paint over uninitialized DRAM); the fix is to paint each screen to completion off-screen, then reveal — the §1 compositor ideal, enabled by persistent screens + pumping the renderer to idle off-screen. JPEG over BMP/RAW: BMP isn't Legato-decodable (only RAW/JPEG/PNG), so it would mean a custom parser + bypassing the `leImageWidget` path and would prove nothing reusable; JPEG reuses Legato's enabled decoder and **is** the album-art pre-load path. RGB888-without-hoops confirmed in `gfx_canvas.c` (per-canvas mode auto-configures the XLCDC layer), so the splash gets full color depth while the steady-state dashboard stays RGB565 to save DDR bandwidth; the 32bpp splash buffer doubles as future album-art decode scratch. Splash kept as an MGS shell (Greg's call) for base-view uniformity even though its only real content is the loaded image; the image widget is code-added since it's runtime data. Loader is a task (not `APP_Initialize`) because SD mount + FatFs + decode block on I/O and need the scheduler. Known one-time-boot roughness (hard splash→dashboard cut; fixed backlight settle vs a real paint-complete signal; baseline-JPEG-only) tracked in §10/§12. | 
40	| 2026-06-26 | **Anti-aliased rounded button corners via a per-instance vtable re-point — no Legato/MCC edits (`ui/widgets/button_aa/widget_button_aa.c`).** The classic skin draws rounded corners with `leRenderer_ArcFill` (hard stepped edges). `ButtonAA_Enable(btn)` makes one shared writable copy of the button vtable, overrides only `_paint`, and points the button's `fn`/`widget.fn` at the copy; the wrapper runs the original paint then, on `DONE` at the supported radius, overdraws the four corners — sampling each corner's extreme (untouched) pixel as backdrop and blending a 1px band from a precomputed coverage mask (`leColorLerp` + `leRenderer_PutPixel`). Wired from `nav_buttons_init()` (nav-only for now; extend by adding call sites). Also added a CLAUDE.md rule: do not modify MCC-generated/Legato code under `config/default/`. Design in [`ui_compositor.md`](ui_compositor.md) §10a. | Editing the skin (the obvious spot) is forbidden — it's vendor/MCC code that regen silently overwrites. `LE_DYNAMIC_VTABLES` (the sanctioned global override) is **not** an MCC knob and is an unguarded `#define 0` in generated `legato_config.h` (can't flip via config, can't `-D`, can't hand-edit) — dead end. A post-render overdraw on the nav canvas has no vendor-legal post-paint hook and fights Legato's damage-repaint (1-frame hard-corner flash). The per-instance re-point exploits that `leWidget.fn` is a *writable* pointer to a const vtable: it needs no config flag, costs one vtable struct + one mask in BSS (static-allocation discipline holds), runs **in-pass** (repaint→AA same paint, no timing window), and is scoped to exactly the buttons we re-point. **Confirmed on hardware** — smooth corners across selected/unselected/pressed states and slide cycles. |
41	| 2026-06-25 | **Re-enabled GFX Canvas Move FX to animate the nav drawer slide (reverses the earlier "FX off, do our own" call).** The nav drawer now slides in/out by animating its OVR1 canvas window position via `gfxcStartEffectMove` (DEC ease-out), rather than snapping. With a concrete slide need this is the textbook canvas-move case (the doc flagged it as where canvas FX earns its weight); rolling our own would just duplicate the FX timer + `GFX_CANVAS_Task` we already have, and the FX timer only ticks during an active move (no steady cost). Open slides −off→0; entry taps switch the highlight (Dashboard also closes); a move-done callback (`nav_fx_done`) disables OVR1 when a close finishes. **Window-clip gotcha (cost a few iterations):** a canvas layer can't sit truly off-screen — the clip emulates negative X by shifting the source pointer + shrinking the window, but it first aligns X *down* to a multiple of 4 (`x &= ~0x3`, non-32bpp) and wraps a row once \|X\| hits the surface width, briefly flashing the panel's left columns; and the layer update busy-waits for the vsync latch, so that bad frame displays before the hide. Fix: slide to the furthest 4-aligned X with \|X\| < NAV_W (`NAV_CLOSED_X`, derived from NAV_W — not a magic number) so the final shown frame is an in-bounds edge sliver, then `nav_fx_done` disables the layer to clear it. | Canvas Move FX over a hand-rolled stepper because the machinery already exists (just was disabled) and it's purpose-built for sliding a layer window with easing; the earlier FX-off decision was speculative (pre-slide). The off-screen constant is derived + documented (points at the exact clip line) rather than hard-coded, accepting a documented coupling to the generated canvas clip — same class as the cache/scratch and HEO-blender couplings. Full decoupling (own the slide via direct XLCDC position stepping) is the fallback if the clip bites again. |
42	| 2026-06-25 | **UI architecture: disable the MGS screen state machine and let the app own screen orchestration, so panels coexist as live, independently-interactive LCDC layers — `ui_manager` + per-screen modules. Authoritative design in [`ui_compositor.md`](ui_compositor.md).** Confirmed in the Legato core that `_state.layerList` is global, `leUpdate` renders/updates **every** attached layer each frame, and `leInput` picks touch across **all** attached layers top-to-bottom — there is no "active screen" render/pick gate. The only thing enforcing one-screen-at-a-time was `le_gen_init.c`'s state machine (`legato_showScreen` tears down the outgoing tree). Turning it off (and working around the MGS dangling-`le_gen_init.h` bug with a `compat/` stub) means we attach multiple panels' roots to different layers and they're all live + interactive at once. **Model:** each panel is authored as its own MGS Screen used as a *widget-tree factory* (`screenInit_` builds, `screenShow_` attaches + raises its `OnShow` composition root); `leAddRootWidget`/`leRemoveRootWidget` re-host a root onto whatever layer we choose. Layers: dashboard=BASE/0, nav=OVR1/1 (resident → "same nav over every view" free), modal song/mode dialog=OVR2/2 (sized to the dialog so live dashboard telemetry shows around it); camera=HEO outside Legato. Two verbs — **coexist** (overlay-as-layer, background live) and **replace** (swap base view on layer 0) — chosen per interaction, both owned by `ui_manager`, so the choice is reversible. `compositor.c` is promoted to `ui_manager`; per-screen/overlay modules own only their widgets+wiring. **This supersedes the earlier "parked surfaces aren't pickable / reveal-then-promote" idea in the doc** — that was a symptom of the state machine, now removed. | Greg's call to author nav + dialogs as separate MGS Screens (cleaner than overlapping layers in one Screen) collided with Legato's one-active-screen model; the resolution was to drop that model entirely rather than fight it, which the global-layerList facts make safe. Disabling the state machine also removes MGS's per-screen switch baggage outright (deleted code, not dormant) and hands us `screenInit/Show` directly. Live-coexistence (vs. freeze) was required because some dashboard telemetry must keep updating under the nav/dialog (the camera already self-updates on HEO). Per-screen modules + a `ui_manager` orchestrator keep each panel's wiring local (composition-root-per-screen) while one top-level module owns the scarce layer budget — matching the MCC-isolation idiom (own files via `user.cmake`). 3 UI layers + camera is the hard ceiling. | 
43	| 2026-06-25 | **The GFX Canvas regen pushed FreeRTOS `heap_1` past 40 KB → silent boot hang (zero DBGU output); raised `configTOTAL_HEAP_SIZE` 40960 → 100000.** Symptom: after the canvas MCC commit (`ed54f37`), marvin produced no DBGU output at all — bisected to that commit (`8de7c64` working). Not the compositor (it was stashed), and not the XLCDC OVR setup (BASE/HEO use the identical `LCDC_ATTRE`/`WAIT_ATTRS_EQ(SIP)` pre-`Start` pattern that already works, so OVR is symmetric). Root cause: the canvas additions (the dynamic `GFX_CANVAS_Task` + extra OSAL/driver allocations on the 4-layer/canvas display path) tipped cumulative `pvPortMalloc` during `SYS_Initialize` past the 40 KB `heap_1`. Because `configUSE_MALLOC_FAILED_HOOK=1` and `vApplicationMallocFailedHook()` is the MCC default (`taskDISABLE_INTERRUPTS(); for(;;){}`), the failed alloc spun with IRQs off **before** `APP_Initialize`/`log_init` (initialization.c:499) ran → no banner, indistinguishable from a dead board. **Two durable follow-ups (both carried):** (1) the heap size is **not** in `FreeRTOS.yml` — it's a raw literal in the generated `FreeRTOSConfig.h`, so the bump is an **MCC re-apply patch** (joins patch #8, also a `FreeRTOSConfig.h` edit) and will silently revert on the next regen → hang returns; set it in the MCC FreeRTOS component if it exposes Total Heap Size, else keep it on the re-apply list. (2) Patch `vApplicationMallocFailedHook` **and** `vApplicationStackOverflowHook` to emit a marker before the spin — a one-line DBGU write would have turned this multi-step bisect into an instant diagnosis. | Same silent-spin footgun already flagged for `vApplicationStackOverflowHook` (Open questions), now confirmed to bite via the malloc path too — heap exhaustion and stack overflow both present as identical dead-board hangs with the stock hooks. `heap_1` (never frees) is correct for marvin's static-allocation discipline, but MCC tasks + Legato OSAL still need it, so its size is load-bearing and must be tracked. 100000 is generous (+60 KB) headroom for now; right-size later once boot logs `xPortGetFreeHeapSize()`. Found by Greg's heap hypothesis after the XLCDC poll-loop theory was ruled out by BASE/HEO symmetry. |
44	| 2026-06-25 | **`GFX_CANVAS_Task` runs at priority 2 (the UI band), set via the gfx_canvas component's Task Priority field — not the generated default of 1.** Band 2 is marvin's UI tier (`LEGATO`, `DRV_MAXTOUCH`, `XLCDC`, `SYS_INPUT`; see 2026-05-21 priority re-tiering); the canvas task joins it as a fifth member. Stack 1024 / 10 ms delay kept (matches the other MCC UI tasks; FX is off so it mostly idles between updates). | The canvas task commits Legato's rendered output to the hardware layers (`gfxcShowCanvas`/`CanvasUpdate`/bind) — it *is* a UI task, peer to `XLCDC_Tasks` and downstream of `LEGATO_Tasks`, so it belongs in the same band under the established rule "a late UI paint is jitter only → UI stays the lowest *active* band and yields to vision (4) and strum-critical (5)." The generated default of **1** is wrong twice over: band 1 is **reserved** (future housekeeping/watchdog), and it would sit an active critical-path task below its UI peers. Same band as Legato (not above) is correct — both are event/short-poll and mostly blocked, and canvas presentation operates on shared state asynchronously, so there's no producer/consumer inversion like the old VideoTask one. Set in the component yml (per the 2026-05-21 "MCC priorities live in yml" rule) so regen reproduces it with **no `tasks.c` re-apply patch**. The dynamic `xTaskCreate` (vs static) is unchanged — consistent with the other MCC tasks on heap_1; static conversion stays a separate carried item. |
45	| 2026-06-25 | **Operator-UI presentation layer = a marvin compositor over the GFX Canvas component: pre-render UI panels into static non-cached RAM surfaces, multiplex the two free LCDC overlay layers (`OVR1`/`OVR2`) across them. Design captured in [`ui_compositor.md`](ui_compositor.md).** The goal is to bring a panel up (or slide it in) instantly without re-rendering or redrawing what's behind it. Confirmed the enabling fact in code: Legato's only "where do I render" knob is the active layer's `pixelBuffer.pixels` (it paints a scratch buffer, then `DRV_XLCDC_BlitBuffer` copies into `drvLayer[activeLayer].pixelBuffer`); there is **no** stock Legato API to render a widget tree into an arbitrary off-screen buffer. **GFX Canvas is exactly that missing indirection** — `GFXC_GetPixelBuffer` hands Legato a canvas object's buffer and `gfxcSetBaseCanvasID` switches which canvas a layer renders into, with `gfxcSetLayer`/show/hide/position/alpha + fade/move on top. Layer budget: `BASE`=background, `OVR1`/`OVR2`=swappable overlays (to be enabled — `XLCDC_TOT_LAYERS` is 2 today), `HEO`=live camera (off-limits). Legato stays the **renderer** (fonts, `song_list`); a thin `ui/` compositor owns surface↔layer multiplexing. Touch handled by **reveal-then-promote** (parked surfaces are non-interactive; promote to a live Legato layer to interact). Phased plan P0–P5 + open questions in the doc. **Design only — no code/MCC yet.** | Reverses the earlier "back off canvas" — that call was made on the **wrong axis**: canvas was dismissed for the *slide animation* (which direct `XLCDC_SetLayerWindowXYPos` stepping handles fine, no framework needed), but the actual problem is the **off-screen surface pool** (render content decoupled from a hardware layer), and that is canvas's literal reason to exist. The two homegrown alternatives lose: DIY pixel-buffer retarget reimplements canvas's per-surface/scratch/binding bookkeeping (~half of canvas, growing once surfaces aren't full-screen); direct-layer-only can present/animate but can't get Legato content *into* a surface. Canvas's earlier objections are addressable, not fatal: it deletes the static `frame_buffer` array, but we *use* the canvas buffers as our surfaces (statically allocated, non-cached per the 2026-06-24 fix), so static-allocation holds; the dynamic `GFX_CANVAS_Task` converts to `xTaskCreateStatic` or rides alongside the existing MCC dynamic tasks. Binding constraint is **layers (2 free), not memory** (~21 MB free in the 32 MB `ram_nocache` after the ISC pool + scratch; full-screen RGB565 ≈ 2 MB, most overlays far less). Resolves spec Q5 for the *presentation* layer (Legato renderer + canvas compositor) without dictating per-screen authoring. |
```
</details></tool-use>

_**Agent (claude-opus-4-8 2026-06-29 13:12:23Z)**_

The journal's decision log is newest-at-top. I'll add a 2026-06-29 entry. Let me also check the splash-provisioning narrative section around line 214 to update the source-of-raw mention:

_**Agent (claude-opus-4-8 2026-06-29 13:12:24Z)**_

<tool-use data-tool-type="read" data-tool-name="Read"><details>
<summary>Tool use: **Read**</summary>
 `./firmware/marvin/docs/journal.md`

```text
209	
210	### 2026-06-28 — Splash loads from QSPI (host→QSPI provisioning over JTAG) — end-to-end on hardware
211	
212	The splash now lives in QSPI NOR, not on the SD card — **confirmed booting with no SD inserted**, splash up in **263 ms** (`SPLASH: 4096000 B from QSPI in 263 ms`).
213	
214	- **Read side (`ui/screens/splash/splash.c`):** `Splash_Load()` dropped the SD/FatFs path (`Storage_Mount` + `SYS_FS_*` + chunked file read) and now does `DRV_SST26_Open` → `DRV_SST26_Read(s_fb, 4,096,000, QSPI_SPLASH_OFFSET)` → `Close`, falling back to the opaque fill only on a flash error. This also removes the SD bring-up (~300 ms) from the splash path entirely — SD still mounts later for catalog/recordings. `DRV_SST26_Read` (CPU) not XDMAC: 263 ms is ~as fast as XDMAC (~225 ms) since the QSPI read dominates and the strongly-ordered framebuffer writes overlap, so XDMAC-for-splash is dropped (~40 ms, not worth it).
215	- **Provisioning (`openocd/program-qspi.{sh,cfg,md}`, `qspi_console.py`):** host→QSPI over JTAG, mirroring the NAND flow — stage an init-and-stop at91bootstrap (DDR up) + a u-boot SF flasher + the blob into DDR, then drive the u-boot console `sf probe`/`erase`/`write`/verify. `splash` / `assets` / `raw` targets (settings region guarded); `shell` mode stages u-boot only for interactive `sf` poking. The **committed NAND-flasher u-boot already has SF** (`sf probe` detects the SST26) — it's the default `UBOOT_BIN`, so no qspiflash build was needed. Bugs found + fixed on first run: u-boot parses args as **hex** (pass lengths in hex), `sf erase` needs **64 KiB-aligned** length for this part (`ERROR -22` otherwise), and the verify must key on `: OK` / absence of `!=` (terse u-boot output substring-matched `Erased`/`were the same` even on failure). Heartbeat dots added — the multi-MB erase/write is silent for ~10-25 s (expected, one-time).
216	- **Boot chain reminder:** the `NAND: ... Copy 0x100000 from 0x40000 to 0x23f00000` lines at boot are at91bootstrap loading the marvin **app** from NAND — normal, unrelated to the splash (which the `from QSPI` line proves comes from QSPI).
217	
218	### 2026-06-28 — QSPI settings store (EEPROM-emulation ring-log) built + stress-validated
```
</details></tool-use>

_**Agent (claude-opus-4-8 2026-06-29 13:12:27Z)**_

Now I'll add the decision-log entry and a session-log note. First the decision-log entry (newest at top, above the 2026-06-28 rows):

_**Agent (claude-opus-4-8 2026-06-29 13:12:37Z)**_

<tool-use data-tool-type="write" data-tool-name="Edit"><details>
<summary>Tool use: **Edit**</summary>

```text
The file /Users/gregmrozek/Projects/microchip/guitar-pic/firmware/marvin/docs/journal.md has been updated successfully. (file state is current in your context — no need to Read it back)
```
</details></tool-use>

_**Agent (claude-opus-4-8 2026-06-29 13:12:40Z)**_

Now add the source-of-raw note to the 2026-06-28 provisioning narrative:

_**Agent (claude-opus-4-8 2026-06-29 13:12:47Z)**_

<tool-use data-tool-type="write" data-tool-name="Edit"><details>
<summary>Tool use: **Edit**</summary>

```text
The file /Users/gregmrozek/Projects/microchip/guitar-pic/firmware/marvin/docs/journal.md has been updated successfully. (file state is current in your context — no need to Read it back)
```
</details></tool-use>

_**Agent (claude-opus-4-8 2026-06-29 13:12:56Z)**_

Docs updated. Now let me review exactly what I'll commit (scoped to the splash work — leaving the unrelated `t1s_link.c` and untracked dirs alone):

_**Agent (claude-opus-4-8 2026-06-29 13:12:57Z)**_

<tool-use data-tool-type="shell" data-tool-name="Bash"><details>
<summary>Tool use: **Bash**</summary>
Review git status and jpg change

`git status --short && echo "--- jpg change summary ---" && git diff --stat -- firmware/marvin/data/ui/splash.jpg`

```text
 M .specstory/history/2026-06-28_13-33-03Z-speed-question-qspi-nand.md
 M .specstory/statistics.json
 M firmware/marvin/data/README.md
 M firmware/marvin/data/ui/splash.jpg
 M firmware/marvin/data/ui/splash.raw
 M firmware/marvin/default/src/net/t1s/t1s_link.c
 M firmware/marvin/docs/journal.md
?? .specstory/history/2026-06-29_13-03-08Z-do-we-have-a.md
?? firmware/marvin/data/ui/make-splash.sh
?? firmware/marvin/docs/sam9x75-chybrid/
?? hardware/t1s-sink/
--- jpg change summary ---
 firmware/marvin/data/ui/splash.jpg | Bin 337735 -> 350453 bytes
 1 file changed, 0 insertions(+), 0 deletions(-)
```
</details></tool-use>

_**Agent (claude-opus-4-8 2026-06-29 13:13:01Z)**_

<tool-use data-tool-type="shell" data-tool-name="Bash"><details>
<summary>Tool use: **Bash**</summary>
Stage splash-related files

`git add firmware/marvin/data/ui/make-splash.sh firmware/marvin/data/ui/splash.raw firmware/marvin/data/ui/splash.jpg firmware/marvin/data/README.md firmware/marvin/docs/journal.md && git status --short`

```text
 M .specstory/history/2026-06-28_13-33-03Z-speed-question-qspi-nand.md
 M .specstory/statistics.json
M  firmware/marvin/data/README.md
A  firmware/marvin/data/ui/make-splash.sh
M  firmware/marvin/data/ui/splash.jpg
M  firmware/marvin/data/ui/splash.raw
 M firmware/marvin/default/src/net/t1s/t1s_link.c
M  firmware/marvin/docs/journal.md
?? .specstory/history/2026-06-29_13-03-08Z-do-we-have-a.md
?? firmware/marvin/docs/sam9x75-chybrid/
?? hardware/t1s-sink/
```
</details></tool-use>

_**Agent (claude-opus-4-8 2026-06-29 13:13:07Z)**_

<tool-use data-tool-type="shell" data-tool-name="Bash"><details>
<summary>Tool use: **Bash**</summary>
Commit splash conversion script and docs

```bash
git commit -m "$(cat <<'EOF'
marvin: add splash jpg->raw conversion script (make-splash.sh)

Convert any image to the 4,096,000-byte RGBA8888 1280x800 splash.raw that
splash.c loads from QSPI. Byte order is the XLCDC layer's native [A,B,G,R]
(0xRRGGBBAA little-endian word) -- not Pillow's default R,G,B,A; verified
against the committed raw. Uses uv + Pillow (no ImageMagick/ffmpeg on host).

Regenerate splash.raw from the (newer) splash.jpg, document the step in
data/README.md, and record the byte-order derivation in the journal.

Co-Authored-By: Claude Opus 4.8 (1M context) <noreply@anthropic.com>
EOF
)"
```

```text
[gui cd4edf2] marvin: add splash jpg->raw conversion script (make-splash.sh)
 5 files changed, 4144 insertions(+), 3825 deletions(-)
 create mode 100755 firmware/marvin/data/ui/make-splash.sh
```
</details></tool-use>

_**Agent (claude-opus-4-8 2026-06-29 13:13:13Z)**_

Committed `cd4edf2` on `gui`. Done:

**Created** `firmware/marvin/data/ui/make-splash.sh` — converts any image → the 4,096,000-byte `splash.raw` (RGBA8888 1280×800, `[A,B,G,R]` byte order), via `uv` + Pillow, with the size assertion baked in.

**Docs:**
- `data/README.md` — new "Boot splash" section documenting the script and the `program-qspi.sh splash` flash step.
- `docs/journal.md` — 2026-06-29 decision-log entry (script + the byte-order derivation) and a note on the 2026-06-28 provisioning narrative.

**Regenerated** `splash.raw` from the newer `splash.jpg` (they'd drifted out of sync) and committed the updated `.jpg` alongside, since the raw now derives from it.

Left untouched (unrelated to this task): the modified `t1s_link.c`, the untracked `docs/sam9x75-chybrid/` and `hardware/t1s-sink/` dirs, and the `.specstory/` files.

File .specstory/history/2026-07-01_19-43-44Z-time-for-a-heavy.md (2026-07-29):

<!-- Generated by SpecStory, Markdown v2.1.0 -->

# 2026-07-01 19:43:44Z

<!-- Claude Code Session 798574ee-b547-4219-9394-b8e0dc9bad97 (2026-07-01 19:43:44Z) -->

_**User (2026-07-01 19:43:44Z)**_

Time for a heavy lift. I want to implement gameplay engine. First, let's map selected song to the dashboard artwork and labels. Note that LABEL widgets that get assigned dyamic strings should all end in camelcase names. fixed labels are all uppercase. see screen_song_select for dynamic string mechanism

---

_**Agent (claude-opus-4-8 2026-07-01 19:43:51Z)**_

This is a marvin task. Let me orient by reading the journal, spec, and the relevant screen code first.

_**Agent (claude-opus-4-8 2026-07-01 19:43:52Z)**_

<tool-use data-tool-type="read" data-tool-name="Read"><details>
<summary>Tool use: **Read**</summary>
 `./firmware/marvin/docs/journal.md`

```text
File content (410KB) exceeds maximum allowed size (256KB). Use offset and limit parameters to read specific portions of the file, or search for specific content instead of reading the whole file.
```
</details></tool-use>

_**Agent (claude-opus-4-8 2026-07-01 19:43:53Z)**_

<tool-use data-tool-type="shell" data-tool-name="Bash"><details>
<summary>Tool use: **Bash**</summary>
Find song select and dashboard source files

`cd /Users/gregmrozek/Projects/microchip/guitar-pic/firmware/marvin && grep -rl "screen_song_select\|song_select\|screen_dashboard\|dashboard" src --include=*.c --include=*.h | grep -v config/default | head -50`

```text
(eval):1: no matches found: --include=*.c
```
</details></tool-use>

_**Agent (claude-opus-4-8 2026-07-01 19:43:58Z)**_

<tool-use data-tool-type="read" data-tool-name="Read"><details>
<summary>Tool use: **Read**</summary>
 `./firmware/marvin/docs/journal.md`

```text
File content (37424 tokens) exceeds maximum allowed tokens (25000). Use offset and limit parameters to read specific portions of the file, or search for specific content instead of reading the whole file.
```
</details></tool-use>

_**Agent (claude-opus-4-8 2026-07-01 19:43:58Z)**_

<tool-use data-tool-type="shell" data-tool-name="Bash"><details>
<summary>Tool use: **Bash**</summary>
Find song select and dashboard source files

`grep -rl "song_select\|dashboard\|screen_song\|screen_dashboard" src | grep -v config/default | head -50`

```text
ugrep: warning: src: No such file or directory
```
</details></tool-use>

_**Agent (claude-opus-4-8 2026-07-01 19:44:02Z)**_

<tool-use data-tool-type="read" data-tool-name="Read"><details>
<summary>Tool use: **Read**</summary>
 `./firmware/marvin/docs/journal.md`

```text
File content (29428 tokens) exceeds maximum allowed tokens (25000). Use offset and limit parameters to read specific portions of the file, or search for specific content instead of reading the whole file.
```
</details></tool-use>

_**Agent (claude-opus-4-8 2026-07-01 19:44:02Z)**_

<tool-use data-tool-type="shell" data-tool-name="Bash"><details>
<summary>Tool use: **Bash**</summary>
Find song select and dashboard source files

`grep -rl "song_select\|dashboard\|screen_song\|screen_dashboard" . --include="*.c" --include="*.h" | grep -v config/default | head -50`

```text
default/src/app.h
default/src/app.c
default/src/ui/ui_manager.h
default/src/ui/screens/video/screen_video.h
default/src/ui/ui_manager.c
default/src/ui/screens/song_select/screen_song_select.c
default/src/ui/screens/video/screen_video.c
default/src/ui/screens/navigation/screen_navigation.c
default/src/ui/screens/dashboard/screen_dashboard.h
default/src/ui/screens/album_art/screen_album_art.h
default/src/ui/screens/dashboard/screen_dashboard.c
default/src/ui/widgets/song_list/widget_song_list.c
default/src/game/gameplay_engine.c
default/src/game/gameplay_select.c
default/src/game/art.h
default/src/game/gameplay_metadata.h
default/src/game/gameplay_select.h
```
</details></tool-use>

_**Agent (claude-opus-4-8 2026-07-01 19:44:07Z)**_

<tool-use data-tool-type="read" data-tool-name="Read"><details>
<summary>Tool use: **Read**</summary>
 `./firmware/marvin/docs/journal.md`

```text
File content (26168 tokens) exceeds maximum allowed tokens (25000). Use offset and limit parameters to read specific portions of the file, or search for specific content instead of reading the whole file.
```
</details></tool-use>

_**Agent (claude-opus-4-8 2026-07-01 19:44:11Z)**_

<tool-use data-tool-type="read" data-tool-name="Read"><details>
<summary>Tool use: **Read**</summary>
 `./firmware/marvin/docs/journal.md`

```text
1	# marvin — Working Journal
2	
3	Running log of planning, decisions, open questions, and work-in-progress for marvin. Newest entries at the top. For *what marvin is* (purpose, subsystems, interfaces, milestones), read [`spec.md`](spec.md) — this journal does not duplicate it.
4	
5	---
6	
7	**2026-07-01 — Dashboard redesign: dedicated SELECT SONG button; top-bar tap retired.** MGS regenerated the Marvin screen with a reworked dashboard: the old `PANEL_BASE_TOP`/`PANEL_BASE_BOTTOM`/`PANEL_SYSTEM_*`/`PANEL_ROBOT_CONTROLS` are gone, replaced by `PANEL_DASHBOARD_TOP`/`_BOTTOM` (+ `_TOP_LEFT`/`_TOP_RIGHT`), and the guitar strum buttons were dropped. Three code effects: (1) **Song select** now opens from a real `BUTTON_DASHBOARD_GAMEPLAY_SELECT_SONG` button (released-callback → `UiManager_OpenSongSelect`), replacing the old header-panel vtable-tap hack in `screen_dashboard.c`. (2) `screen_video.c`'s fullscreen input-gate retargeted from `BASE_TOP/BASE_BOTTOM` to `DASHBOARD_TOP/DASHBOARD_BOTTOM`. (3) This regen dropped **all** MGS auto-event wiring, so the hamburger (renamed `BUTTON_NAV_HAMBURGER`, now under `DASHBOARD_TOP_LEFT`) is wired explicitly in `ScreenNavigation_Setup` via `setPressedEventCallback`; the orphaned `event_Marvin_BUTTON_SYSYEM_NAVIGATION_OnPressed` was removed. The guitar strum glue in `manual_input.c` is kept as-is (orphaned but preserved) — the `ManualControl` actuator logic stays even though the UI no longer drives it, so the strum buttons can be reattached later. **Pending hardware test / build.**
8	
9	**2026-07-01 — HEO video levels expansion (gamma CLUT).** The captured source is mildly range-compressed vs the panel's full 0..255 — corpus measurement (active area, borders excluded): black cluster ~5 (dead border pedestal ~13, cropped out), white ceiling ~233, nothing ≥235. The HEO CBHS limited-range black-level block is **YCbCr-only** (datasheet §6.2.6.7 / SAM9X7 DS), so it can't touch our RGB888 HEO input; instead we use the HEO **per-component gamma CLUT** (works on true RGB, `HEOCFG1.GAM`), loaded once with a linear levels-expansion curve (`out = clamp((in−5)·255/228)`, `VIDEO_LEVELS_BLACK=5`, `WHITE=233`). Display-only — the DDR capture is untouched so the detector/gameplay see raw pixels — and free at scanout. Loaded in `UiManager_Initialize` while GAM/CLUTEN are clear (required to write `LCDC_HEOCLUT[256]`); `XLCDC_SetLayerRGBColorMode` rewrites `HEOCFG1` with `GAM(0)` on every bind, so `heo_bind` re-asserts `GAM` after it. Fixed curve (no runtime knob for the *values*), but a **`gamma <on|off>` console command** toggles the whole expansion on/off (`UiManager_SetVideoLevels`, gates `GAM` in `heo_bind` + requests a rebind) for A/B eyeballing on the panel. **Code-complete, pending hardware test** — the ~5/233 pedestal/ceiling may differ per Wii/converter, retune `VIDEO_LEVELS_*` if needed. Earlier "blacks already at 0" was wrong — conflated the rare true-0 outliers with the ~5 cluster; corrected here.
10	
11	**2026-07-01 — Rounded AA frame around the windowed video + nav→OVR2.** The windowed video (HEO, a hard rectangle) now gets a 1px rounded frame with anti-aliased corners, matching the dashboard panels (`0x404040` = `SCHEME_PANEL` `LE_SCHM_SHADOWDARK`, radius 6). Since the video is on HEO (not a canvas), the `PanelAA` backdrop-blend trick can't reach it — the frame is a **direct-driven ARGB_4444 overlay on OVR1, above HEO**, carrying true per-pixel alpha so the LCDC composites it over the video. Z-order is `OVR2>OVR1>HEO>BASE` (`VIDPRI(0)`), and the open nav drawer covers the video's left edge, so the frame must sit *below* nav → **nav moved OVR1→OVR2**, frame took OVR1. The GFX canvas framework has no 4444 mode (`gfxColorMode` only 5551/8888), so the overlay is driven directly via the XLCDC PLIB (splash/HEO-style), buffer filled once from a rounded-rect SDF: corner-cut opaque black (dashboard backdrop), 1px stroke, transparent interior; alpha AA on the stroke→video edge. New `ui_manager` verbs: `UiManager_VideoOverlayShow/Hide` (OVR1) and `UiManager_ShowNavLayer/HideNavLayer` (nav on OVR2 via `bind_canvas`, which pokes RGB565 each open since album-art leaves OVR2 in RGBA8888). Reveal-time OVR1 RGB565 poke dropped (OVR1 users now self-poke). Frame lifecycle = "windowed video visible": shown by `ScreenVideo_ShowWindowed`, hidden on fullscreen enter and song-select open. Layer map now: BASE=dash, HEO=video, OVR1=video-frame/song-select-dialog, OVR2=nav/album-art (frame⇎dialog and nav⇎album-art are time-exclusive; frame hidden whenever video is). Design in [`ui_compositor.md`](ui_compositor.md) §16. **Code-complete, pending hardware test.** Watch for CSI-2 capture stalls — the overlay adds an always-on ~41 MB/s OVR1 read while windowed. **Future:** this OVR1 overlay is also where a **per-frame gameplay HUD** (note-highway markers, hit/miss, detected-note boxes) would be drawn over the video — direct buffer raster, no Legato (canvas framework can't own it and per-frame Legato repaint is too heavy), must be fast/minimal-overhead (incremental redraw), and double-buffered with a vsync address flip to avoid tearing. HUD coords map to the *displayed* window, so source-derived positions apply the §15 active-area crop+scale. See `ui_compositor.md` §16.1.
12	
13	**2026-07-01 — Runtime active-picture detection + HEO source-crop.** The component→HDMI (Wii) source frames its active raster with dead black bars whose thickness varies by console/converter, so the active area is **detected at runtime**, not hardcoded. Offline analysis of the 101-frame `docs/gh3_screens` corpus (720×480 captures): active area ≈ **716×448 @ (0,15)** (top 15 / bottom 17 / right 4 / left 0), and — key finding — the bars are **not** black=0; they sit at a ~13 pedestal, the *same* level as in-video black (so a `>0` test can't separate them). What separates cleanly is brightness: border max ≤ ~14, content ≥ ~145, so a **fixed luma threshold (max of B,G,R > 40)** splits them with wide margin and no pedestal dependence (validated: recovers the exact box on 99/101 frames, all 101 pass a ≥700×420 gate). Bonus: 716×448 = 1.598 ≈ the panel's 1.600, so cropping to the active area makes fullscreen essentially aspect-correct. Implementation: `video.c` detector (`Video_GetActiveRect`) scans inward from each edge (bounded to the deepest border the min-size gate allows, so a dark loading frame is cheap), unions the bright bounds over 16 *bright* frames (dark frames find no content and are skipped), then locks if ≥700×420 — one-shot per capture arm, reset on re-arm/source-size change, full-frame fallback until locked. The compositor (`ui_manager` `heo_bind`) consumes the rect as the **HEO source crop**: offset the frame base by `y*stride + x*bpp`, size `HEOCFG4` to the active w/h, skip cropped columns via `XSTRIDE = (src_w-active_w)*bpp` (matches the GFX driver's own `FB_TYPE_SZ*(resx-sizex)`); `heo_frame_latch` adds the same offset per ring slot; `heo_reconcile` rebinds when the rect changes (detection flipping full→cropped). Applies to both windowed and fullscreen. **Code-complete, pending hardware test.**
14	
15	**2026-07-01 — Tap-to-fullscreen live video (`screen_video`).** Tap the live video on the dashboard to blow it up to fullscreen (HEO stretch-to-fill across 1280×800); tap anywhere to shrink back to the windowed 720×480 rect. New `screens/video/screen_video.{c,h}` module — a screen module *without a canvas* (the video is on the HEO hardware layer, compositor-owned), so it owns only the interaction: a `touchDownEvent` re-pointed onto `Marvin_PANEL_DASHBOARD` (the full-screen layer-0 catch-all under the IGNOREPICK `root0`). Relies on Legato's touch **bubbling** (`legato_input.c` walks `targetWidget->parent` until a widget calls `leWidgetEvent_Accept`) — plain panels never accept, so a video-region tap bubbles up to the dashboard panel; windowed→tap-in-rect enters fullscreen via `UiManager_VideoShow(0,0,BASE_W,BASE_H)`. To exit from anywhere, fullscreen gates picking off on `Marvin_PANEL_BASE_TOP` + `Marvin_PANEL_BASE_BOTTOM` (the two subtrees holding every interactive dashboard widget) by clearing `LE_WIDGET_ENABLED` (flag-only, no repaint — same gate as `ui_manager`'s `panel_set_pickable`), so every tap then resolves to the dashboard panel and exits. Windowed placement is now owned by `SCREEN_VIDEO_WIN_*` in `screen_video.h` (moved out of `ui_manager`'s `VIDEO_WIN_*`); `ui_manager` calls `ScreenVideo_ShowWindowed()` at reveal and on song-select close. `base_discard_reconcile` follows the video rect, so fullscreen discards BASE DMA across the whole panel (free bandwidth win). Design in [`ui_compositor.md`](ui_compositor.md) §14. **Pending hardware test.** (The windowed HEO rect (280,76) lines up with the `VIDEO_STREAM` placeholder panel — abs (280,77) once its `BASE_BOTTOM`→`BASE_CENTER` parent offsets are summed. Fullscreen can't be entered with the nav drawer open: nav is modal (`UiManager_SetDashboardPickable(false)`), so the dashboard — and the video tap — is un-pickable while it's open.)
16	
17	**UI architecture — nav drawer complete; song/mode-select dialog is the next UI step.** The canvas compositor + per-screen-module model is built and validated on hardware: `ui_manager` orchestrates screens (string table + `screenInit/Show`; the MGS screen state machine is disabled, worked around with the `compat/le_gen_init.h` stub), the dashboard is its own MGS Screen on BASE, and the nav drawer is its own MGS Screen (`Navigation`) re-hosted onto OVR1 — they coexist live (no active-screen gate; `leUpdate`/`leInput` cover all attached layers). `LE_LAYER_COUNT`=3 is pinned via the never-shown `LayerBudget` screen. **Nav drawer is feature-complete:** slides in/out via canvas Move FX (`NAV_CLOSED_X` dodges the window-clip row-wrap; mid-slide reversal cancels the in-flight move), single-active highlight (Dashboard closes, others switch), clean close, rounded buttons with anti-aliased corners (`ui/widgets/button_aa/widget_button_aa.c`, per-instance vtable re-point — see `ui_compositor.md` §10a). Authoritative design + the window-clip/alignment gotchas in [`ui_compositor.md`](ui_compositor.md); decisions 2026-06-25. **Next (decided 2026-06-29): migrate to MGS's single-master-screen / layer-screen model** — one master Legato screen named `Marvin` with one layer per panel (dashboard, nav, song-select, dialogs…), replacing the current "separate 1-layer MGS Screen per panel, manually re-hosted, `LE_LAYER_COUNT` pinned by the fake `LayerBudget` screen" approach. MGS then derives `LE_LAYER_COUNT` and auto-associates each layer-screen with its canvas, so the `LayerBudget` hack, the `compat/le_gen_init.h` stub, and the disconnect/re-host dance all go away; `ui_manager` shrinks to buffer assignment + `show_layer`/`hide_layer` verbs. **Splash stays separate/manual** (pre-Legato RGBA8888) on a canvas slot outside the layer-screen range. Authoritative model + direction now in [`ui_compositor.md`](ui_compositor.md) §0. SongSelect (MGS screen already generated, committed `1e16ac9`) becomes a Marvin layer-screen rather than a standalone Screen. The earlier "parked surfaces aren't pickable / reveal-then-promote" framing is **superseded** (a state-machine artifact).
18	
19	**Song-select operator UI — scrollable list widget built & validated on hardware.** Custom Legato widget `ui/song_list.{h,c}` (a hand-written `leWidget` subclass) renders the SELECT SONG setlist (tier badge + bold title + dim artist + right-aligned duration), driven by a decoupled row-provider callback (no catalog dependency); drag-scroll with time-based kinetic inertia, tap-to-select. Bring-up via the `songlist` console command + a catalog-backed demo provider (`ui/song_list_demo.{c,h}`) — scroll/select/opaque-fill confirmed on hardware. **Bringing it up surfaced and fixed a real Legato/GFX2D cache-coherency bug** (see decision log 2026-06-24): the CPU-rendered scratch buffer was cacheable, so the 2D-engine blit leaked stale pixels through opaque widgets — fixed by placing the scratch in non-cached DDR. **Next:** author the full SELECT SONG screen in MGS (album art + catalog-fed metadata panel + difficulty/mode/Select), and the **tier / career-setlist data model** (the `tier` badge needs the deferred catalog tier column). Two upstream Microchip Legato/gfx bugs to file (decision log).
20	
21	**Song catalog loader — built and committed; exercised on hardware via the `catalog`/`songlist` console commands.** New `game/catalog.{h,c}` maps the recognizer's `(setlist, index)` → human labels (title/artist/bpm/length) from `<card>/games/gh3-wii/songs.csv`, so the UI/high-score display shows names instead of `#4`. Flat **CSV** (decided over the spec's JSON for the same reasons `results` is CSV — no on-device tokenizer, `FF_FS_MAX_FILES=1`, static buffers, pandas/Excel-editable). The two CSV helpers were extracted out of `results.c` into a shared `util/csv.{h,c}` and the catalog reuses them. Lazy-loads once into a fixed `[GP_N_SONGS]` static cache (file closed after load), so lookups are O(n) in RAM and don't fight `results.csv` for the single FatFs handle. `catalog` console command (`reload` / `ls` / `<main|bonus> <index>`) validates the path against a checked-in seed catalog (`data/games/gh3-wii/songs.csv`). Columns: `setlist,index,title,artist,album,bpm,length_s,year,genre,difficulty`. `title`/`artist`/`album` are real, sourced from the `SONGS` table in `tools/fetch_gh3_cover_art.py` (incl. proper UTF-8 — *Héroes del Silencio*, *Mauvais Garçon*); that script gained a `--catalog` mode that also fills `year`/`genre` from MusicBrainz on a networked run. `bpm`/`length_s`/`difficulty` are reserved-but-blank (GH3 surfaces no per-song difficulty; the authentic signal is the career tier, deferred). Catalog is labels only: a missing/stale card degrades to "Unknown song" and never touches recognition (compile-time in flash). **Deferred:** the stale-catalog version warning — `export_c.py` doesn't emit `GP_METADATA_VERSION` yet (open item below). **Next SD consumer:** album-artwork pre-cache (spec §4.8.7) — directory structure is now locked (`art/{small,large}/<setlist>-<NN>.{jpg,png}`, one size-tier subdir per DDR cache). **Built 2026-06-30** (`game/art.{c,h}`, decision log): all covers decoded once into static RGB888 DDR caches during the splash, `(setlist,index)`→`leImage*` lookup, song-select strip wired; large tier is a 508×208 strip with a difficulty-colored fade baked offline. Dashboard small-thumbnail consumer still pending (no MGS slot yet).
22	
23	**T1S inter-node link — built and working (marvin ↔ guitar).** marvin is the PLCA **coordinator** (node 0) on a 10BASE-T1S bus (LAN8651 over FLEXCOM4 SPI); hand-authored stack in `default/src/net/t1s/`. It sends the actuator command over T1S to the `guitar` follower node (id 2), which actuates the Wii GPIOs (guitar G1+G2 proven). Followers announce presence via a heartbeat (ethertype `0x88B6`); the `t1s` and `nodes` console commands report link/credits/per-node presence. Transport is behind `MARVIN_FRETBOARD_TRANSPORT={UART,T1S}` (T1S default on the `t1s` branch). The `fretboard` node (id 1) firmware is now **written, T1S-only** (fretboard journal 2026-06-17): it streams its 17-byte frame to marvin **and** drives the `guitar` node directly — its on-device model infers the bitmask and sends it peer-to-peer to `02:..:02`. marvin's RX side needed no changes — `fretboard_link.c`'s T1S frame handler already parses the frame from node id 1 (`DETECTOR_ADC_FRETBOARD`) and the node-table + heartbeat-presence demux already cover it. **Next (marvin side):** **active-source arbitration** — both marvin (timing pipeline) and the fretboard now address the guitar (`02:..:02`), so marvin needs active-detector/active-guitar selection to ensure exactly one source drives at a time (the fretboard's SW0 is an interim manual arm; until then, don't run marvin's timing pipeline to the guitar while the fretboard is armed). Then fretboard hardware bring-up. PoDL is design-direction only. Detail in [`../../../docs/t1s-podl-link.md`](../../../docs/t1s-podl-link.md); decision log entry 2026-06-17.
24
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

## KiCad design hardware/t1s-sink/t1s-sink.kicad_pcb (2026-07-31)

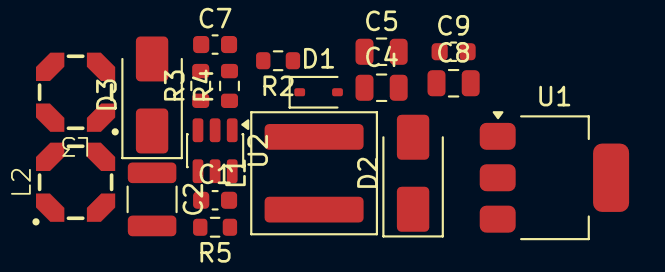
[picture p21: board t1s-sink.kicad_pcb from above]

Board: 2 copper layers, 19 parts (0 on the bottom side), 12 nets, no tracks yet.

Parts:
C1, C9: 0.1uF 50V; C_0603_1608Metric
C2: 10uF 50V; C_1210_3225Metric
C4, C5, C8: 10uF 16V; C_0805_2012Metric
C7: 120pF 50V; C_0603_1608Metric
D1: 1N4148WS; D_SOD-323
D2, D3: MBRA140T3G; D_SMA
L1: 22uH 5A; L_Coilcraft_XAL6060-XXX
L2: 33uH, 0.31A; LPD4012
L3: 33uH 0.31A; LPD4012
R2: 52.3k; R_0603_1608Metric
R3: 4.7; R_0603_1608Metric
R4: 10.0k; R_0603_1608Metric
R5: 82; R_0603_1608Metric
U1: MCP1804x-3302xDB; SOT-223-3_TabPin2
U2: MCP16301x-xCH; SOT-23-6

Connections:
+3.3V: C8.1, C9.1, U1.1 (OUT)
+5V: C4.1, C5.1, D1.2 (A), L1.2, R2.1, U1.3 (IN)
GND: C2.2, C4.2, C5.2, C7.2, C8.2, C9.2, D2.2 (A), L3.3, R4.2, U1.2 (GND), U2.2 (GND)
unnamed: C1.1, R5.2
unnamed: C7.1, R3.2
unnamed: D1.1 (K), R5.1, U2.1 (BOOST)
unnamed: C1.2, D2.1 (K), L1.1, U2.6 (SW)
unnamed: D3.2 (A), L3.2
unnamed: L2.2, L3.1
unnamed: L2.4, L3.4
unnamed: R2.2, R3.1, R4.1, U2.3 (Vfb)
VBUS: C2.1, D3.1 (K), U2.4 (EN), U2.5 (V_{IN})

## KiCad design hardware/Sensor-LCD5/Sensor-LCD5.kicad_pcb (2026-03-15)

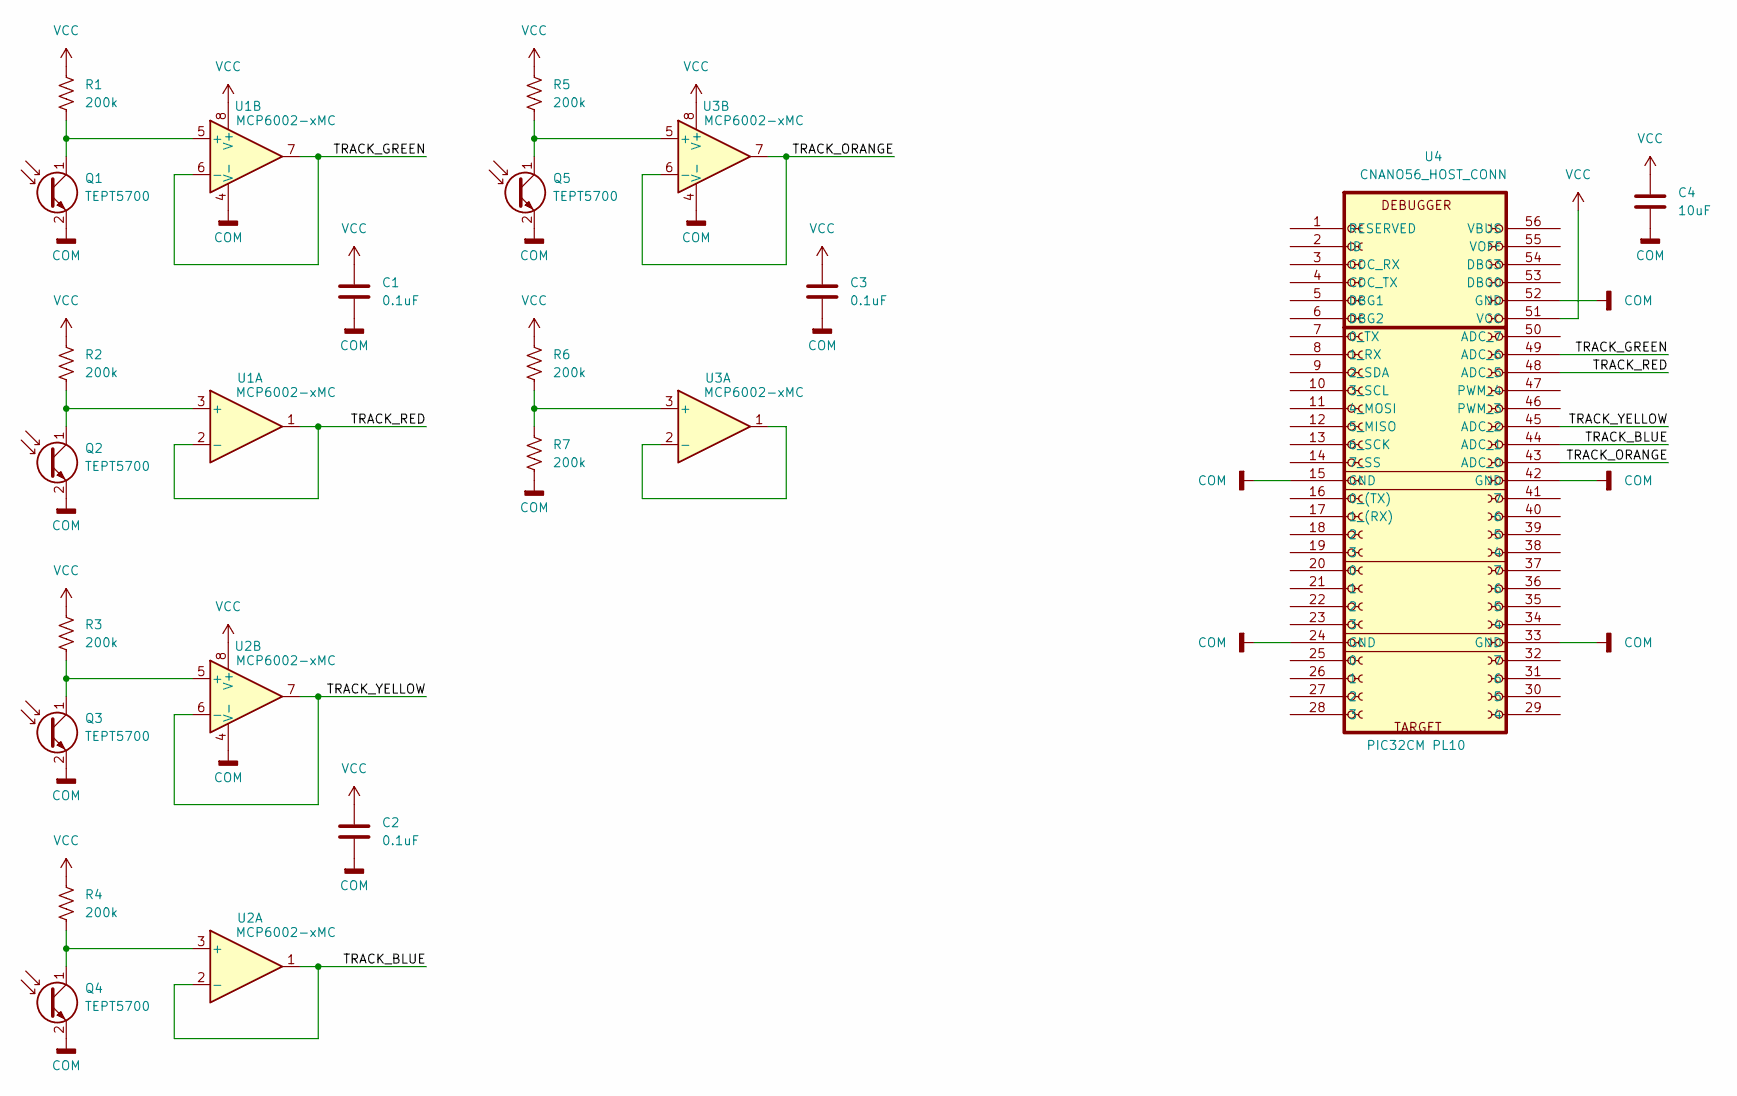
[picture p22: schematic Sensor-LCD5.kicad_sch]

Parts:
C1, C2, C3: 0.1uF; C_0603_1608Metric
C4: 10uF; C_0805_2012Metric
Q1, Q2, Q3, Q4, Q5: TEPT5700; LED_D5.0mm_FlatTop
R1, R2, R3, R4, R5, R6, R7: 200k; R_0603_1608Metric
U1, U2, U3: MCP6002-xMC; DFN-8-1EP_3x2mm_P0.5mm_EP1.75x1.45mm
U4: PIC32CM PL10; CNANO_Connector_56; PARTGROUP Mechanical devices,Connectors,Pin heade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

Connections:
/TRACK_BLUE: U2.1, U2.2 (-), U4.44 (ADC_1)
/TRACK_GREEN: U1.6 (-), U1.7, U4.49 (ADC_6)
/TRACK_ORANGE: U3.6 (-), U3.7, U4.43 (ADC_0)
/TRACK_RED: U1.1, U1.2 (-), U4.48 (ADC_5)
/TRACK_YELLOW: U2.6 (-), U2.7, U4.45 (ADC_2)
COM: C1.2, C2.2, C3.2, C4.2, Q1.2 (E), Q2.2 (E), Q3.2 (E), Q4.2 (E), Q5.2 (E), R7.2, U1.4 (V-), U1.9 (V-), U2.4 (V-), U2.9 (V-), U3.4 (V-), U3.9 (V-), U4.15 (GND), U4.24 (GND), U4.33 (GND), U4.42 (GND), U4.52 (GND)
unnamed: Q1.1 (C), R1.2, U1.5 (+)
unnamed: Q2.1 (C), R2.2, U1.3 (+)
unnamed: Q3.1 (C), R3.2, U2.5 (+)
unnamed: Q4.1 (C), R4.2, U2.3 (+)
unnamed: Q5.1 (C), R5.2, U3.5 (+)
unnamed: R6.2, R7.1, U3.3 (+)
unnamed: U3.1, U3.2 (-)
VCC: C1.1, C2.1, C3.1, C4.1, R1.1, R2.1, R3.1, R4.1, R5.1, R6.1, U1.8 (V+), U2.8 (V+), U3.8 (V+), U4.51 (VCC)

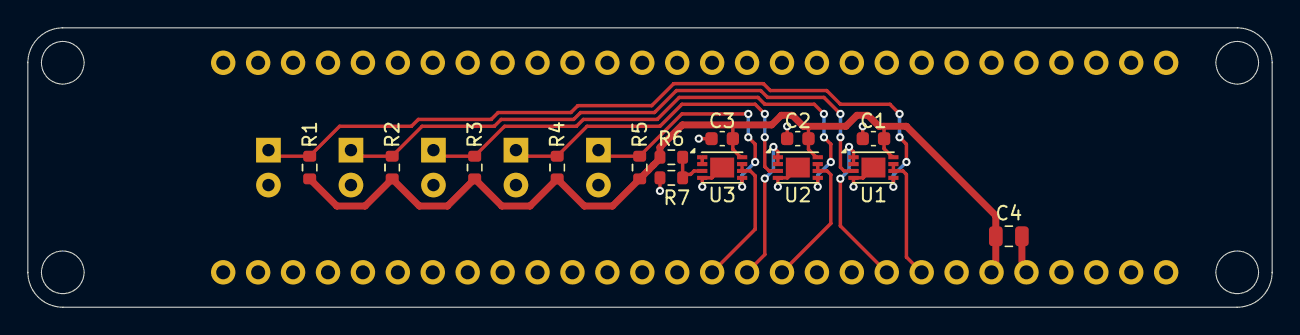
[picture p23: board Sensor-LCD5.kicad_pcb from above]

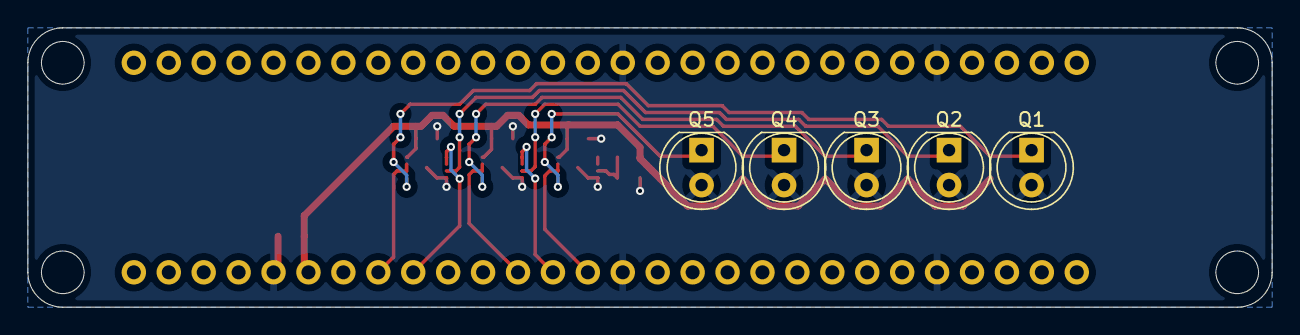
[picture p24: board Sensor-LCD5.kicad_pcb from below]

Board: 2 copper layers, 90.5 x 20.3 mm, 20 parts (5 on the bottom side), 14 nets.

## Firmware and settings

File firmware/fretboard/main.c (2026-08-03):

#include <stddef.h>
#include <stdbool.h>
#include <stdint.h>
#include <stdlib.h>
#include "definitions.h"
#include "fret_scan.h"
#include "data_stream.h"
#include "fretboard_config.h"
#include "t1s_detector.h"
#include "status_led.h"
#include "cli.h"
#include "model_infer.h"

#if MODEL_INFER_STREAMING
#include "model_infer_stream.h"
#define ADC_Q_LEN 16   /* ISR->main sample queue; streaming must consume every sample */
#endif

/* Guitar actuation is armed via the `arm on|off` CLI command or marvin's control
 * channel (0x88B9 opcode 0x01) — last writer wins, no lockout. Boots disarmed:
 * silent on the guitar command channel until armed; disarming sends one final
 * release then goes silent again. (Interim manual "active detector" gate until
 * marvin coordinates active-detector/guitar selection.) LED0 is the T1S liveness
 * heartbeat (status_led.c), independent of the arm state. */

/* Latest inference (main loop writes, ISR reads). Single byte → atomic on M0+. */
static volatile uint8_t s_latest_cmd;

/* Gated command driven this tick (ISR writes, main loop forwards to the guitar).
 * Also the applied_mask reported in the data frame. */
static volatile uint8_t s_current_cmd;

/* Effective actuation-armed state this tick (ISR writes, main loop forwards so the
 * detector gates the guitar command path — disarmed goes silent). */
static volatile bool s_actuation_active;

#if MODEL_INFER_STREAMING
/* SPSC sample queue: the ISR pushes one scan/tick, the main loop steps the
 * stateful streaming model once per sample (it must consume every sample in
 * order). Stays near-empty while inference keeps up (>240 Hz). */
static volatile uint16_t s_adc_q[ADC_Q_LEN][FRET_COUNT];
static volatile uint16_t s_q_wr;      /* ISR-advanced write index */
static volatile uint16_t s_q_rd;      /* main-advanced read index */
#endif

static bool actuation_armed(void)
{
    /* Arm state is owned by t1s_detector — set by the `arm` CLI command or marvin's
     * control channel (last writer wins). */
    return T1SDetector_Armed();
}

void Callback_TC0 (TC_TIMER_STATUS status, uintptr_t context)
{
    fret_scan_all();

#if MODEL_INFER_STREAMING
    uint16_t wi = s_q_wr;
    for (int c = 0; c < FRET_COUNT; c++)
    {
        s_adc_q[wi % ADC_Q_LEN][c] = fret_scan_result((fret_channel_t)c);
    }
    s_q_wr = (uint16_t)(wi + 1u);   /* publish the sample to the main loop */
#else
    uint16_t scan[FRET_COUNT] = {
        fret_scan_result(FRET_GREEN),
        fret_scan_result(FRET_RED),
        fret_scan_result(FRET_YELLOW),
        fret_scan_result(FRET_BLUE),
        fret_scan_result(FRET_ORANGE),
    };
    model_infer_push(scan);   /* sample the window at a clean 240 Hz */
#endif

    /* The heavy inference runs in the main loop; here we just gate the most
     * recent result and stream the (ADC + driven mask) frame to the coordinator.
     * The main loop forwards s_current_cmd to the guitar. */
    bool armed = actuation_armed();
    uint8_t cmd = armed ? s_latest_cmd : 0u;
    s_current_cmd = cmd;
    s_actuation_active = armed;
    /* commanded_mask carries marvin's teacher command (0 unless it's teaching) —
     * paired atomically with this scan as the edge-ai training label. */
    data_stream_send(cmd, T1SDetector_TeacherMask());
}

int main(void)
{
    SYS_Initialize(NULL);

    fret_scan_init();
    data_stream_init();
    T1SDetector_Initialize();
    StatusLed_Initialize();
    CLI_Initialize();
#if MODEL_INFER_STREAMING
    model_infer_stream_init();
#else
    model_infer_init();
#endif

    TC0_TimerCallbackRegister( Callback_TC0, (uintptr_t)NULL );
    TC0_TimerStart();

    /* Model selection lives as a byte in t1s_detector (written by the CLI or
     * marvin's 0x88B9 opcode 0x03); this loop applies changes to the active
     * engine. Both boot MODEL_SEL_DEFAULT so the first pass is a no-op. */
    uint8_t applied_sel = MODEL_SEL_DEFAULT;

    while (true) {
        uint8_t sel = T1SDetector_ModelSel();
        if (sel != applied_sel) {
            model_infer_set_sel(sel);   /* recomputes the need-table; keeps the ring */
            applied_sel = sel;
        }
        /* Run inference only when its output is used (armed) or when the model
         * must stay warm for an instant arm (disarmed but not streaming — e.g.
         * menus). During a capture (disarmed + streaming) the inferred command
         * is discarded, so skip the heavy step: it keeps the main-loop pass
         * under the 240 Hz tick so the data-frame flush never falls behind. An
         * overrun lets the ISR overwrite the staged frame before it is sent,
         * which surfaces as an fb_seq gap in the training stream. */
        bool run_infer = s_actuation_active || !T1SDetector_StreamEnabled();
#if MODEL_INFER_STREAMING
        /* Always drain the ISR->main sample queue so it can't overflow; step the
         * (heavy) streaming model only when the result is needed. */
        while (s_q_rd != s_q_wr)
        {
            uint16_t ri = s_q_rd;
            uint16_t s[FRET_COUNT];
            for (int c = 0; c < FRET_COUNT; c++) { s[c] = s_adc_q[ri % ADC_Q_LEN][c]; }
            if (run_infer) { s_latest_cmd = model_infer_stream_step(s); }
            s_q_rd = (uint16_t)(ri + 1u);
        }
#else
        if (run_infer) { s_latest_cmd = model_infer_run(); }
#endif
        /* Forward the gated command to the guitar (edge-triggered + refreshed) and
         * service the MAC-PHY / data-frame flush / presence heartbeat, then the
         * LED heartbeat and the CLI. */
        T1SDetector_SetCommand(s_current_cmd, s_actuation_active);
        T1SDetector_Tasks();
        StatusLed_Tasks();
        CLI_Tasks();
    }

    return EXIT_FAILURE;
}

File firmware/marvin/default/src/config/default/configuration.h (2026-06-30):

/*******************************************************************************
  System Configuration Header

  File Name:
    configuration.h

  Summary:
    Build-time configuration header for the system defined by this project.

  Description:
    An MPLAB Project may have multiple configurations.  This file defines the
    build-time options for a single configuration.

  Remarks:
    This configuration header must not define any prototypes or data
    definitions (or include any files that do).  It only provides macro
    definitions for build-time configuration options

*******************************************************************************/

// DOM-IGNORE-BEGIN
/*******************************************************************************
* Copyright (C) 2018 Microchip Technology Inc. and its subsidiaries.
*
* Subject to your compliance with these terms, you may use Microchip software
* and any derivatives exclusively with Microchip products. It is your
* responsibility to comply with third party license terms applicable to your
* use of third party software (including open source software) that may
* accompany Microchip software.
*
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
* IN NO EVENT WILL MICROCHIP BE LIABLE FOR ANY INDIRECT, SPECIAL, PUNITIVE,
* INCIDENTAL OR CONSEQUENTIAL LOSS, DAMAGE, COST OR EXPENSE OF ANY KIND
* WHATSOEVER RELATED TO THE SOFTWARE, HOWEVER CAUSED, EVEN IF MICROCHIP HAS
* BEEN ADVISED OF THE POSSIBILITY OR THE DAMAGES ARE FORESEEABLE. TO THE
* FULLEST EXTENT ALLOWED BY LAW, MICROCHIP'S TOTAL LIABILITY ON ALL CLAIMS IN
* ANY WAY RELATED TO THIS SOFTWARE WILL NOT EXCEED THE AMOUNT OF FEES, IF ANY,
* THAT YOU HAVE PAID DIRECTLY TO MICROCHIP FOR THIS SOFTWARE.
*******************************************************************************/
// DOM-IGNORE-END

#ifndef CONFIGURATION_H
#define CONFIGURATION_H

// *****************************************************************************
// *****************************************************************************
// Section: Included Files
// *****************************************************************************
// *****************************************************************************
/*  This section Includes other configuration headers necessary to completely
    define this configuration.
*/

#include "user.h"
#include "device.h"

// DOM-IGNORE-BEGIN
#ifdef __cplusplus  // Provide C++ Compatibility

extern "C" {

#endif
// DOM-IGNORE-END

// *****************************************************************************
// *****************************************************************************
// Section: System Configuration
// *****************************************************************************
// *****************************************************************************



// *****************************************************************************
// *****************************************************************************
// Section: System Service Configuration
// *****************************************************************************
// *****************************************************************************
/* TIME System Service Configuration Options */
#define SYS_TIME_INDEX_0                            (0)
#define SYS_TIME_MAX_TIMERS                         (5)
#define SYS_TIME_HW_COUNTER_WIDTH                   (32)
#define SYS_TIME_HW_COUNTER_PERIOD                  (4294967295U)
#define SYS_TIME_HW_COUNTER_HALF_PERIOD             (SYS_TIME_HW_COUNTER_PERIOD>>1)
#define SYS_TIME_CPU_CLOCK_FREQUENCY                (800000000)
#define SYS_TIME_COMPARE_UPDATE_EXECUTION_CYCLES    (1210)


/* File System Service Configuration */

#define SYS_FS_MEDIA_NUMBER               (1U)
#define SYS_FS_VOLUME_NUMBER              (1U)

#define SYS_FS_AUTOMOUNT_ENABLE           false
#define SYS_FS_MAX_FILES                  (1U)
#define SYS_FS_MAX_FILE_SYSTEM_TYPE       (1U)
#define SYS_FS_MEDIA_MAX_BLOCK_SIZE       (512U)
#define SYS_FS_MEDIA_MANAGER_BUFFER_SIZE  (2048U)
#define SYS_FS_USE_LFN                    (1)
#define SYS_FS_FILE_NAME_LEN              (255U)
#define SYS_FS_CWD_STRING_LEN             (1024)

/* File System RTOS Configurations*/
#define SYS_FS_STACK_SIZE                 1024
#define SYS_FS_PRIORITY                   1

#define SYS_FS_FAT_VERSION                "v0.15"
#define SYS_FS_FAT_READONLY               false
#define SYS_FS_FAT_CODE_PAGE              437
#define SYS_FS_FAT_MAX_SS                 SYS_FS_MEDIA_MAX_BLOCK_SIZE
#define SYS_FS_FAT_ALIGNED_BUFFER_LEN     512
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

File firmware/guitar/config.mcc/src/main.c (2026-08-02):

/*******************************************************************************
  Main Source File

  Company:
    Microchip Technology Inc.

  File Name:
    main.c

  Summary:
    This file contains the "main" function for a project.

  Description:
    This file contains the "main" function for a project.  The
    "main" function calls the "SYS_Initialize" function to initialize the state
    machines of all modules in the system
 *******************************************************************************/

// *****************************************************************************
// *****************************************************************************
// Section: Included Files
// *****************************************************************************
// *****************************************************************************

#include <stddef.h>                     // Defines NULL
#include <stdbool.h>                    // Defines true
#include <stdlib.h>                     // Defines EXIT_FAILURE
#include "definitions.h"                // SYS function prototypes
#include "t1s_follower.h"               // 10BASE-T1S follower (LAN8651 over SERCOM0 SPI)
#include "cli.h"                        // operator CLI on the SERCOM1 debug UART
#include "status_led.h"                 // LED0 liveness / link-state heartbeat


// *****************************************************************************
// *****************************************************************************
// Section: Main Entry Point
// *****************************************************************************
// *****************************************************************************

int main ( void )
{
    /* Initialize all modules */
    SYS_Initialize ( NULL );

    T1SFollower_Initialize ( );
    StatusLed_Initialize ( );
    CLI_Initialize ( );

    while ( true )
    {
        /* Maintain state machines of all polled MPLAB Harmony modules. */
        SYS_Tasks ( );

        /* Service the T1S link: receive marvin's command frames and drive
         * the Wii-guitar GPIOs. */
        T1SFollower_Tasks ( );

        /* Non-blocking LED0 heartbeat encoding liveness + on-bus state. */
        StatusLed_Tasks ( );

        /* Operator CLI on the debug UART (status / manual btn / tap). */
        CLI_Tasks ( );
    }

    /* Execution should not come here during normal operation */

    return ( EXIT_FAILURE );
}


/*******************************************************************************
 End of File
*/

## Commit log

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2026-03-26 Implement button pushing. Is mostly working on "School's Out". Issue with logic when two of same color one after the other.
    [main.c]
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2026-05-14 Remove emirror project as it was reference project that is no longer needed now that marvin project is functioning.
    [configuration.h, gfx_maxtouch_controller.yml, pin_configurations.csv]
2026-05-14 MCC: LVDSPLL fix to 444 MHz + drop unused HEO/OVR2 layers
    MCC config update on the XLCDC Driver component:
    LVDSClockMul = 37 (was implicitly 29 from old MCC default)
    LVDSClockFrac = 174763 (was 699051)
    LVDSClockDivPMC = 2 (was 4)
    XLCDC_TOT_LAYERS dropped to 2 (BASE + OVR1 only; HEO and OVR2
    were enabled by default but unused).
    Resulting plib_xlcdc.c emits PMC_PLL_CTRL1_MUL(37-1) | FRACR(174763)
    and PMC_PLL_CTRL0_DIVPMC(2-1) for the LVDSPLL — ~444.5 MHz output,
    correct for the 10.1" 1280x800 panel's pixel-clock × 7 LVDS-bit-clock
    requirement. Eliminates the flicker that came with the old 175 MHz
    config.
    Dropping HEO/OVR2 fr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
    [configuration.h]
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2026-05-15 Yellow tinge resolved: drop refresh to 50 Hz (LVDSPLL 410.76 MHz)
    MCC config update to the XLCDC Driver component sets LVDSPLL output to
    410.76 MHz, producing a 58.68 MHz pixel clock and 50.00 Hz frame rate
    at our 1440x815 timing. This drops the LVDS bit clock from ~444 Mbps
    to ~411 Mbps, giving the receiver enough eye-margin to recover bits
    correctly with this cable's SI characteristics.
    Empirical sweep recorded in yellow_tinge.md:
    30 Hz @ 246 Mbps - clean, slight flicker
    40 Hz @ 329 Mbps - clean, no flicker
    45 Hz @ 370 Mbps - clean, no flicker
    50 Hz @ 411 Mbps - clean, no flicker <- chosen
    52 Hz @ 427 Mbps - clean (closest tested clean)
    54 Hz @ 444 Mbps - yellow on overlay le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
    [configuration.h]
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2026-05-16 MCC: add MaxTouch driver for 10.1" panel — touch working
    MXT336T driver wired to DRV_I2C0 with 1280×800 resolution. MCC also
    regenerated the GFX display component for NVDI 10.1", I²C driver,
    core, sys_input, and vision (CSI/CSI2DC/ISC) components — same
    content but file timestamps / formatting updated by the regen.
    Verified working: touches register cleanly through SYS_INP into
    Legato. Initial loop-on-init was a loose touch flex cable, not a
    software issue.
    [configuration.h, gfx_maxtouch_controller.yml, pin_configurations.csv]
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2026-05-19 log: lightweight severity-filtered printf shim; convert callers
    Drop Harmony's SYS_CONSOLE/SYS_COMMAND/SYS_DEBUG stack and replace
    with a thin in-tree log module. The Harmony stack pulled in three
    extra services with their own task/mutex/queue plumbing; debugging
    unexplained boot hangs through that surface burned a session before
    we backed out. The new module is ~80 lines we own.
    src/log.{h,c}:
    - log_init / log_set_level / log_get_level
    - log_printf / log_vprintf with printf-style format
    - LOG_ERROR / LOG_WARN / LOG_INFO / LOG_DEBUG convenience macros
    - Output via libc vprintf → xc32_monitor → DBGU (no service tasks)
    - Single FreeRTOS mutex, taken only when scheduler is runnin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
    [configuration.h]
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2026-05-21 mcc: revert SYS_Initialize peripheral order broken by USB regen
    The USB CDC host regen reordered SYS_Initialize so TC0/FLEXCOM6/XLCDC
    inits ran before MMU_Initialize and AIC_INT_Initialize. With the AIC
    not yet owning the interrupt vector table, the FLEXCOM6 ISR never
    fired — TC358743 probe wedged on its first I²C write
    (OSAL_SEM_Pend(transferDone, WAIT_FOREVER) blocked forever) and video
    + display were dead. FBL heartbeat kept printing because it doesn't
    depend on a peripheral interrupt.
    Reverted to the pre-regen order: MMU → AIC → WDT-disable → TC0 →
    FLEXCOM6 → XLCDC. Display + capture come back on first boot. Logged
    as patch #6 in the marvin journal's MCC re-apply list.
    Als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
    [fretboard_link.c]
2026-05-21 usb: assert VBUS GPIOs at app level, ahead of consumer init
    The Harmony USB host driver's portPowerEnable callback is set but
    never invoked, so VBUS_AH_PC27/PC31 stayed deasserted and the SAM9X75
    Curiosity's external USB power switches never enabled. Asserting the
    GPIOs directly powers the bus.
    Pulling VBUS + USB_HOST_BusEnable out of the fretboard_link task into
    APP_Initialize: the host stack is shared across future USB consumers
    (HID, MSC, etc.), so the bus bring-up doesn't belong to any one class
    driver. fretboard_link now only registers the CDC attach handler.
    Power up confirmed on hardware. Detection still pending — separate
    work item.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
    [fretboard_link.c]
2026-05-21 usb host: bind CDC class driver to EDBG composite bridges
    The host CDC class driver hardcoded bInterfaceProtocol == AT_V250 (0x01)
    in F_USB_HOST_CDC_InterfaceAssign for both the single-interface and IAD
    paths. EDBG-style USB-to-UART bridges (the on-board debugger CDC on the
    fretboard board) declare the comm interface with bInterfaceProtocol == 0
    (NO_CLASS_SPECIFIC). TPL/IAD match accepted the device but the per-
    interface check rejected it, the interrupt pipe never opened, the CDC
    instance flipped to STATE_ERROR, and the app-level attach handler never
    fired. Relax both checks to (AT_V250 || NO_CLASS_SPECIFIC). Logged as
    patch #7 in journal.md so it gets re-applied after future MCC regens.
    A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
    [configuration.h]
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2026-05-21 fretboard_link: serialize CDC control-pipe requests in open_cdc
    LineCodingSet and ControlLineStateSet were issued back-to-back; the host
    stack silently drops the second while the first is still in flight on
    the control pipe, so DTR/carrier never asserts and the EDBG bridge
    keeps its UART TX idle. Add an s_ctrl_done binary semaphore signaled
    from the ISR-context SET_LINE_CODING_COMPLETE / SET_CONTROL_LINE_STATE_COMPLETE
    event cases, and wait between requests in open_cdc — same pattern as
    the existing s_write_done.
    [fretboard_link.c]
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2026-05-22 freertos: widen priority budget to 8 and re-tier tasks by failure cost
    Bumps configMAX_PRIORITIES from 5 to 8 and re-shuffles every task
    priority so the layout is intentional rather than the as-found mix
    where producers ran below consumers (VideoTask at 1, CvMarvinV1 at 2)
    and most MCC tasks were piled into a single band. Active bands now go
    USB host (5) > timing/actuator (5) > capture/detector (4) > device/UI
    (2-3); reserve bands sit above for ISR-deferred work and below idle
    for housekeeping. MCC component yml files carry the new priorities so
    regens preserve the layout. Hand-written constants in video,
    cv_marvin_v1, timing_pipeline, fretboard_link, perf_log are aligned to
    the same scheme;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
    [gfx_maxtouch_controller.yml]
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2026-05-22 perf-log: emit PERF_REC_TASK_HIGHWATER at 1 Hz per registered task
    Drain task now iterates a static handles array and samples
    uxTaskGetStackHighWaterMark for each registered task, emitting one
    record per pass alongside the existing DROP heartbeat. Each marvin task
    module captures its TaskHandle_t from xTaskCreateStatic and self-
    registers via PerfLog_RegisterTaskForHighwater — perf_log doesn't reach
    into them. Five active tasks × 24 B/record × 1 Hz = 120 B/s.
    Closes the host-side gap on the FreeRTOS-analytics carry-forward: HWM
    trends now render in the marvin-perf viewer's RTOS tab.
    [fretboard_link.c, perf_log.c]
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2026-05-22 perf-log: schema v2 — STRIP + TASK_RUNTIME records
    Replaces fixed PATCH (5×5 per-fret thumbnails) with variable-length STRIP
    records carrying a kind-tagged BGR888 region; adds TASK_RUNTIME for per-
    task state/priority/run-time-counter snapshots alongside the existing
    HWM emitter. Host decoder, analyzer, and viewer all pick up the new types.
    Firmware:
    - perf_log_records.h bumps PERF_LOG_SCHEMA_VERSION to 2; defines
    perf_strip_kind_t (SENSING=0, STRIKE=1; 256 codes) and the runtime body
    - perf_log.c adds the STRIP queue + sample_and_emit_runtimes (1 Hz,
    static TaskStatus_t buf[16] via uxTaskGetSystemState — no malloc)
    - cv_marvin_v1.c emits sensing+strike strips between detect_frame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
    [perf_log.c]
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2026-05-29 udphs: patch driver for multi-IRP DMA arming + bump MCC queue depths
    The journal's "lever 1" plan (pipeline CDC writes for 2-3× perf-log
    throughput) had a hidden gotcha: the stock UDPHS device driver only
    programs the DMA channel in IRPSubmit's queue-empty branch. IRPs
    appended to a non-empty queue link in via iterator->next but never get
    armed for transmission — Tasks_ISR_DMA advances irpQueue=irp->next on
    completion but doesn't re-program DMA hardware. Result: only the first
    IRP of any batch ever transmits.
    Patch is additive (no refactor of existing IRPSubmit body): new helper
    F_DRV_USB_UDPHS_DEVICE_ArmDmaForIrp mirrors the inline DMA-program block
    (both DEVICE_TO_HOST and HOST_TO_DEVI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
    [configuration.h]
2026-05-29 perf-log: throughput pipeline (sink ring, drain refactor, Fletcher, single MAX_BYTES)
    Subsystem overhaul that, paired with the UDPHS driver patch in the prior
    commit, takes sustained perf-log throughput from a ~1.88 MB/s ceiling
    with state drops to 2.77 MB/s clean (185×32 sensing + 290×32 strike,
    60 fps, every record type at 100% delivery).
    Several changes that each fixed a different symptom:
    - N=3 sink staging ring + counting semaphore (perf_log_sink_cdc.c).
    Replaces single staging buffer + binary s_write_done. Producer takes
    a credit, fills s_tx_ring[s_tx_head], submits non-blocking, advances
    head; ISR WRITE_COMPLETE returns one credit. Single producer + FIFO
    bulk-IN completion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
    [perf_log.c]
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2026-06-01 mcc: enable INCLUDE_xTaskGetIdleTaskHandle + INCLUDE_xTaskGetHandle
    Flips two FreeRTOS INCLUDE_ flags via the MCC FreeRTOS component
    (FREERTOS_INCLUDE_XTASKGETIDLETASKHANDLE,
    FREERTOS_INCLUDE_XTASKGETHANDLE) so perf_log can register the idle task
    for absolute CPU% accounting and look up MCC-named tasks by string at
    init time. Regen also reorders some unrelated USB CDC defines in
    configuration.h and include lines in definitions.h — benign noise from
    the same MCC pass.
    [configuration.h]
2026-06-01 perf-log: v3 schema — detector / actuator / timing tuning visibility
    Pivots the perf-log channel from "prove the wire works" (v1/v2 integrity
    story, complete) to "show what the algorithms are thinking." Schema v2 → v3
    with three new/extended record types and full per-task CPU accounting.
    Wire format (perf_log_records.h):
    - DETECTOR_CONFIG: cv_marvin_v1 sample coords, thresholds, color filter
    weights — host needs these to render sample dots / threshold lines onto
    STRIP canvases at correct pixel locations.
    - ACTUATOR: per-Send intended/asserted masks, strum_dir, producer_id (the
    arbitration signal invisible from the wire byte alone), last CDC ack
    result + timestamp.
    - TIMING ext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
    [fretboard_link.c, perf_log.c]
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2026-06-01 marvin-perf: RTOS view shows per-task CPU% snapshot
    Host-side: compute_cpu_snapshot in analyze.py — last-two TASK_RUNTIME
    records per task, uint32-wrap-safe Δ, normalized against Σ across all
    emitting tasks. Wired into /rtos endpoint and mirrored in JS for live
    mode (state.rtos was never populated by the WS path before, so the tab
    was empty under live capture). Per-task table grew a cpu% column;
    busy / idle / other surfaced as a header block.
    Firmware bug: PERF_TASK_IDLE was registering as NULL because PerfLog_Start
    runs from APP_Initialize — pre-scheduler — and xTaskGetIdleTaskHandle()
    returns NULL until vTaskStartScheduler creates the idle task. Idle's
    run_time_counter spilled int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
    [perf_log.c]
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2026-06-02 marvin-perf: stop live page freeze when fretboard records flow
    Two issues compounded into a hung browser tab when fretboard was attached
    and STAMP+FRETBOARD_RAW were enabled:
    1. The per-Read PERF_STAGE_FBL_READ_COMPLETE stamp emitted at 240 Hz —
    diagnostic during bring-up but doubled the timeline marker count
    under live capture. Removed the emit; left the enum slot reserved
    with a comment for any future sub-frame USB-latency tuning. Per-Read
    timing is still recoverable offline from FRETBOARD_RAW.ts_counter.
    2. Timeline used Plotly SVG scatter which rebuilds the DOM on every
    redraw — fine at 1k points, hard freeze past ~10k. Auto-switch to
    `scattergl` above 5k stamps; s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
    [fretboard_link.c]
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2026-06-04 edge-ai: fretboard data-sync (atomic sensor+actuator+seq) + exporter modes
    Root-cause fix for the cross-stream label<->feature skew that floored
    Phase-2 strum timing. The fretboard now stamps each frame with the actuator
    bitmask it is driving and a monotonic sample counter, so sensor and label are
    paired atomically on-device instead of joined across marvin's TX/RX clocks.
    Wire-format break (flash fretboard + marvin together):
    - fretboard: data frame 12->17 B (`sample_seq` u32 + `applied_mask` u8);
    `cmd_receive_current_mask()` getter; seq advances per tick so dropped sends
    show as gaps.
    - marvin: `perf_rec_fretboard_raw_t` 28->32 B; PERF_LOG_SCHEMA_VERSION 3->4;
    RX parser reads the 17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
    [fretboard_link.c, perf_log.c]
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2026-06-04 fretboard: standalone MODEL_DRIVEN int8 inference (model_infer, SW0/LED, ISR-decoupled)
    New MODEL_DRIVEN build mode runs the edge-ai int8 model on-device and drives the
    controller buttons standalone (marvin disconnected):
    - model_infer.c/.h: 60x5 input ring + last-timestep-only int8 conv (integer-only,
    no FPU) + integer output threshold + strum monostable. Active model is a
    swappable model_def_t pointer (model_infer_set_model) for per-difficulty weights.
    - main.c: build-time FRETBOARD_MODE (MODEL_DRIVEN default). SW0 (PB03, active-low
    momentary, debounced) toggles model control; LED0 (PB02) shows state; boots
    disabled (outputs released). Inference runs in the MAIN LOOP, not the 240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
    [main.c]
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2026-06-04 fretboard: deploy window-85 streaming model; guard inference modules (RAM footgun)
    Deploy model: 16ch window-85 (full receptive field), streaming inference, strum
    thresh 0.80 -- runs standalone at a clean 240 Hz with ~1-tick latency and plays
    hard mode well. Window-85 (vs 60) was the real strum fix: it stops zero-padding
    the part of the RF where the photo->strum cue lives (mono precision/recall
    .942/.981 -> .985/.994, glitches -> 0).
    Robustness: shared fretboard_config.h holds FRETBOARD_MODE + MODEL_INFER_STREAMING
    (default 1 = streaming). model_infer.c is guarded #if \!MODEL_INFER_STREAMING and
    model_infer_stream.c #if MODEL_INFER_STREAMING, so BOTH files can stay in the
    project but only t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
    [main.c]
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2026-06-08 marvin: add FT4232H EEPROM tooling + OpenOCD JTAG debug config
    Debug the SAM9X75 over the onboard FT4232H (channel A) with OpenOCD — no macOS
    driver swap needed; libusb claims the JTAG interface despite AppleUSBFTDI.
    - openocd/: sam9x75-chybrid.cfg (ARM926EJ-S debug, per-board FTDI_SERIAL select) + README
    - ftdi/: ft4232h-chybrid.conf + flash-eeprom.sh to program the FT4232H 93LC46B with
    board identity and a unique serial (channels A/B/D=D2XX, C=VCP) + README
    Note: the per-channel VCP/D2XX flag is honored on Windows only; Linux/macOS still
    enumerate all four channels. The serial/identity applies on every OS.
    [sam9x75-chybrid.cfg]
2026-06-08 marvin: document FT4232H/JTAG reset+clock pinout, wire nSRST and RTCK
    Channel-A pinout on the cHybrid FT4232H is now a known quantity:
    TCK=AD0, TDI=AD1, TDO=AD2, TMS=AD3, nRST=AD5, RTCK=AD7 (AD4/AD6 N/C, no nTRST).
    sam9x75-chybrid.cfg: add nSRST (open-drain, -oe 0x20), reset_config srst_only
    srst_open_drain srst_nogate, srst delay 300, and RTCK adaptive-clock note.
    Verified on hardware: 'reset halt' lands in boot ROM (pc=0x44); 'adapter speed 0'
    engages RCLK adaptive clocking.
    [sam9x75-chybrid.cfg]
2026-06-09 marvin: WIP JTAG load-to-RAM (mechanism proven, blocked on clean boot env)
    Adds the JTAG 'load marvin into DDR and run' dev flow (no SD), reusing
    at91bootstrap to init DDR. Mechanism is proven end-to-end: marvin loads over
    JTAG (~517 KB in 3.4 s) and boots into FreeRTOS.
    - sam9x75-chybrid.cfg: robust reset for this auto-booting board (slow clock +
    retry-halt on reset-deassert-post) so 'reset halt' reliably catches the core.
    - load-ram.cfg / load-ram.sh: reset halt -> run at91bootstrap to the return of
    hw_init() (DDR up) -> load marvin -> jump to 0x23f00000. Needs I-cache
    invalidate + ARM-state forcing (handled in the proc).
    KNOWN-BLOCKED (see journal): the board's factory image auto-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
    [load-ram.cfg, sam9x75-chybrid.cfg]
2026-06-09 marvin: JTAG load-to-RAM working end-to-end (DDR init + marvin boots)
    The JTAG dev flow now works on macOS: at91bootstrap is run to the return of
    hw_init() to bring up clocks(266MHz)+DDR3L, then marvin is loaded into DDR and
    launched. marvin boots into FreeRTOS (MMU/caches on, running from DDR).
    Key fixes that made it work:
    - adapter speed 0 (RTCK adaptive clocking, AD7): mandatory — at fixed TCK OpenOCD
    desyncs when at91bootstrap switches the master clock (was misread as a crash).
    - break at hw_init()'s return (computed from the bootstrap ELF) so DDR is up,
    WDT disabled, MMU/caches still off — the env marvin expects.
    - invalidate I-cache (arm mcr 15 0 7 5 0 0) after each load_image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
    [load-ram.cfg]
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2026-06-09 marvin: macOS JTAG dev loop — repeatable load-to-RAM, VS Code debug, microSD
    The OpenOCD reset config was never actually resetting the SoC (-oe-only nSRST,
    no srst pulse_width), which masqueraded as "DDR3L isn't re-runnable / needs a
    power-cycle". Adopt the known-good Microchip class-material reset machinery:
    push-pull nSRST (-data/-oe), srst_pulls_trst, 500 ms reset pulse, a reset-init
    event that disables the watchdog + MMU/caches, and an SRAM work area (fast loads).
    With a real reset, `reset init` resets a running marvin, so load-ram.sh is a
    single-session, repeatable dev loop with no physical power-cycle.
    - sam9x75-chybrid.cfg: example-based reset machinery + FTDI_SERIAL selection;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
    [load-ram.cfg, sam9x75-chybrid.cfg]
2026-06-09 marvin: use known-provenance init-and-stop at91bootstrap for JTAG load
    Replace the mystery at91bootstrap.elf with sam9x7-boot-none-4.0.13.elf, built
    from at91bootstrap v4.0.13 sam9x75_curiosity_pro_bkptnone_defconfig
    (CONFIG_INIT_AND_STOP, W632GU6NB12I DDR; the cHybrid maps to the curiosity_pro
    variant — red LED on PC14). It inits clocks+DDR then loops, so marvin_load_ram
    drops the objdump/bl-hw_init/breakpoint machinery: load -> resume -> wait -> halt
    -> load marvin -> jump. Validated: repeatable from a running marvin, no
    power-cycle.
    [load-ram.cfg]
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2026-06-10 marvin: speed up load-ram (~20s -> ~5s); record flicker baseline
    Re-enable arm7_9 dcc_downloads + fast_memory_access and switch RTCK -> 6 MHz fixed
    TCK for the 517 KB marvin transfer once the bootstrap has finished switching clocks
    (these were dropped in the init-and-stop rewrite). Document that the small
    bootstrap load's DCC/fast-memory warnings are harmless. Record the load-ram
    overlay-flicker hypothesis + good-run PMC clock baseline in the journal.
    [load-ram.cfg]
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2026-06-10 marvin: fix load-ram overlay flicker — run bootstrap to BKPT_NOTIFY_DONE
    The init-and-stop at91bootstrap is designed to run main() to completion and stop
    at crt0's own bkpt (CONFIG_BKPT_NOTIFY_DONE). load-ram was instead breaking at
    hw_init()'s return — stopping mid-main() and skipping the rest of low-level init
    (the slow-clock switch, etc.) — which left marvin's display flickering
    intermittently (never on SD boot, same binary). Now we resume the bootstrap and
    let its own bkpt halt us (full init done), then load marvin. Validated clean
    across 10+ repeated loads with the display connected.
    Speed: re-enable DCC for a ~4s transfer; fast_memory_access stays off (unsafe).
    Cleanup: drop the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
    [load-ram.cfg, sam9x75-chybrid.cfg]
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2026-06-12 marvin: serial operator console (embedded-cli on FLEXCOM2)
    Add an interactive command console on FLEXCOM2 (115 200 8N1), on its
    own channel separate from the DBGU log/printf chatter. Rejected
    Harmony SYS_CONSOLE/SYS_COMMAND: MCC-config-coupled, lands in
    regenerated files, heavy indirection. Instead a small in-tree module
    in the shape of fretboard_link/perf_log — owns the USART plib
    directly, fully static, kept out of MCC via user.cmake.
    - console/console.{h,c}: one FreeRTOS task drains the FLEXCOM2 RX ring
    on a 1-byte read-threshold notification, feeds embedded-cli, and
    dispatches a static binding table (status, detect, active, timing,
    manual, fret, strum) into the existing Detector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
    [fretboard_link.c]
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2026-06-12 fauxmote: Phase 1 investigation — discovery+pairing solved, esp_hidd ruled out
    Worked the HID-device path far enough to prove what does and doesn't work
    against a real Wii, and to extract the data the custom-SDP path will need.
    Solved (on hardware):
    - Discovery: the Wii's SYNC scan uses a limited inquiry — advertise with
    ESP_BT_LIMITED_DISCOVERABLE + COD 0x002504, set after esp_hidd init (which
    otherwise overrides the Class of Device).
    - Legacy PIN pairing: SSP disabled; GAP PIN_REQ answered with the host's
    BD_ADDR reversed (console-SYNC bonding flow). Wii opens an ACL link.
    Ruled out — esp_hidd cannot emulate a Wiimote:
    - With a valid record, the Wii reads our SDP then disconn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
    [main.c]
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2026-06-12 fauxmote: Phase 2 done — Wiimote report state machine; Wii assigns us
    Implemented the Wiimote report responder so a real Wii fully initializes us as
    an assigned controller (verified on hardware).
    - wiimote.c: answer the Wii's HID output reports — EEPROM read 0x17->0x21 (accel
    calibration at 0x16/0x20, error for >0x16FF), status 0x15->0x20, write 0x16->0x22
    ack, reporting-mode 0x12 / LEDs 0x11 / IR-enable 0x13,0x1a acks — and a static
    task streaming 0x30 core-button reports every 15ms for keep-alive. Built with
    explicit bytes (no bitfields); logic modeled on rnconrad/WiimoteEmulator.
    - bt_hid_device.c: route each L2CAP frame to Wiimote_HandleRx; notify on close.
    - status_led.c: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
    [main.c]
2026-06-13 fauxmote: Step A — serial test CLI + connection management
    Adds a manual test/operator interface and proper connection lifecycle on top of
    the working Wiimote emulation.
    - console_cli.c: esp_console REPL with commands pair, stop, reconnect, unlink,
    status, btn, tap. Commands are thin pass-throughs over the module API (Marvin
    will drive the same Wiimote_*/Fauxmote_* functions, not the CLI).
    - Boots idle; pair arms the HID L2CAP listeners for that sync window and stop tears
    them down. Servers are armed per-pairing-window (not at boot / not auto-re-armed)
    — re-arming leaked Bluedroid L2CAP slots because device-initiated reconnect uses
    client connects that never consume the listen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
    [console_cli.c, main.c]
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
